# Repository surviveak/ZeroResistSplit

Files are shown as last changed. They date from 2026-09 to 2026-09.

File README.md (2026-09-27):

# ZeroResistSplit

**ZeroResistSplit** is a low-resistance 2-to-1 filament splitter/merger designed for a dedicated TPU path plus a regular-filament path. The goal was to reduce the drag created by steep PTFE bends and abrupt internal transitions while keeping the assembly compact, printable, and compatible with common 4 mm OD PTFE tubing and the original Bambu Lab 4-to-1 PTFE splitter quick-connect fittings.

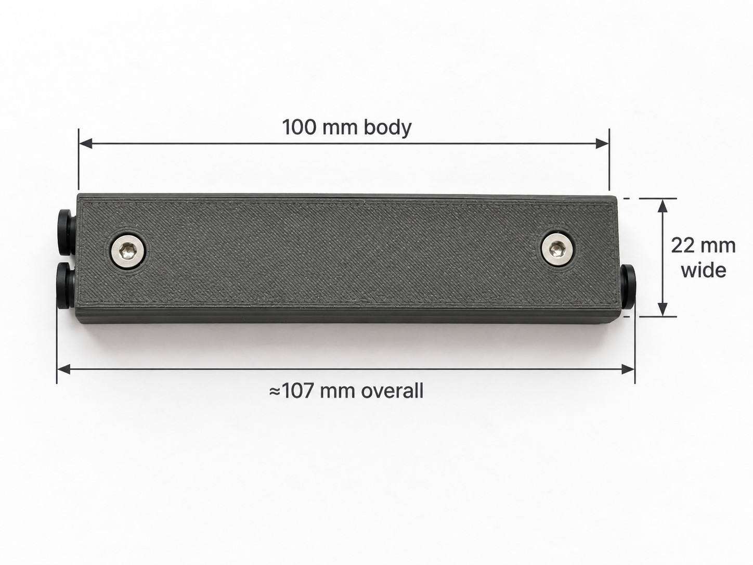
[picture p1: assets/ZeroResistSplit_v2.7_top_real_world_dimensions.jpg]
ZeroResistSplit v2.7 top-view dimensions


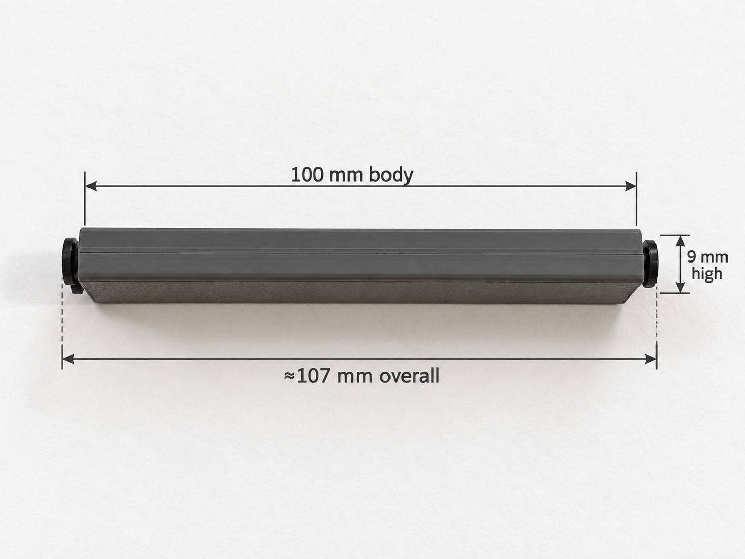
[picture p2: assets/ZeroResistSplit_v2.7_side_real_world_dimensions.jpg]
ZeroResistSplit v2.7 side-view dimensions


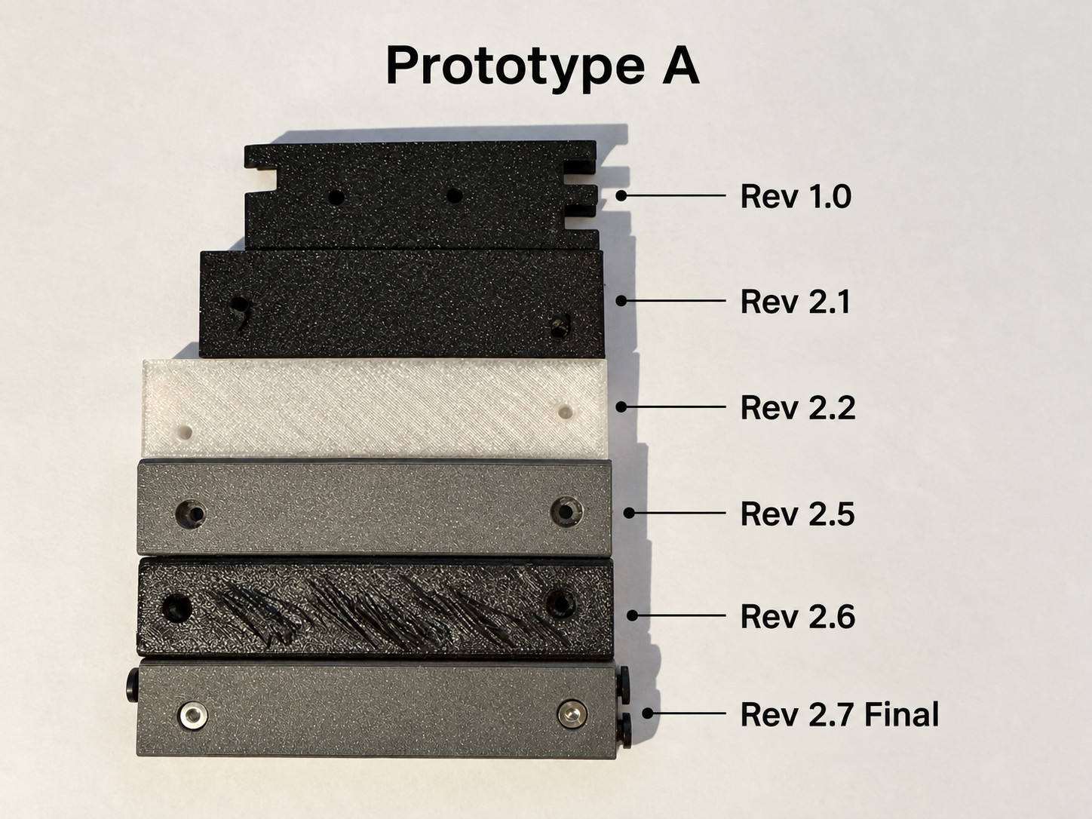
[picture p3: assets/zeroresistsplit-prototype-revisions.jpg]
ZeroResistSplit Prototype A revision progression through v2.7 Final


### Installed on the Bambu Lab H2C

The following photos show the completed v2.7 splitter installed in the working filament path.

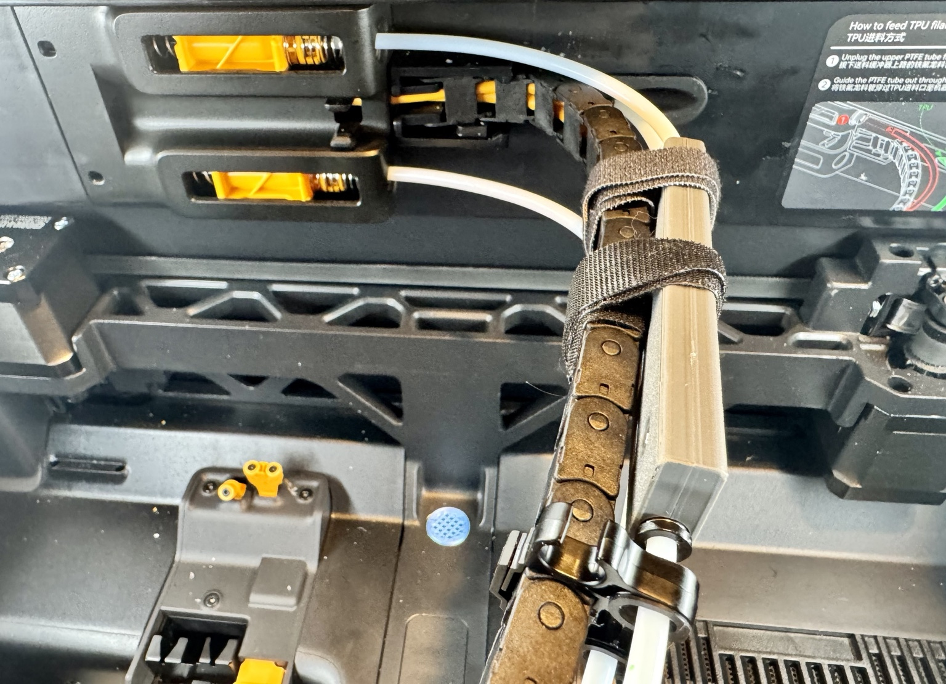
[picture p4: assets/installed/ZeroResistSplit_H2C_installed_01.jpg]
ZeroResistSplit v2.7 installed on Bambu Lab H2C — internal view


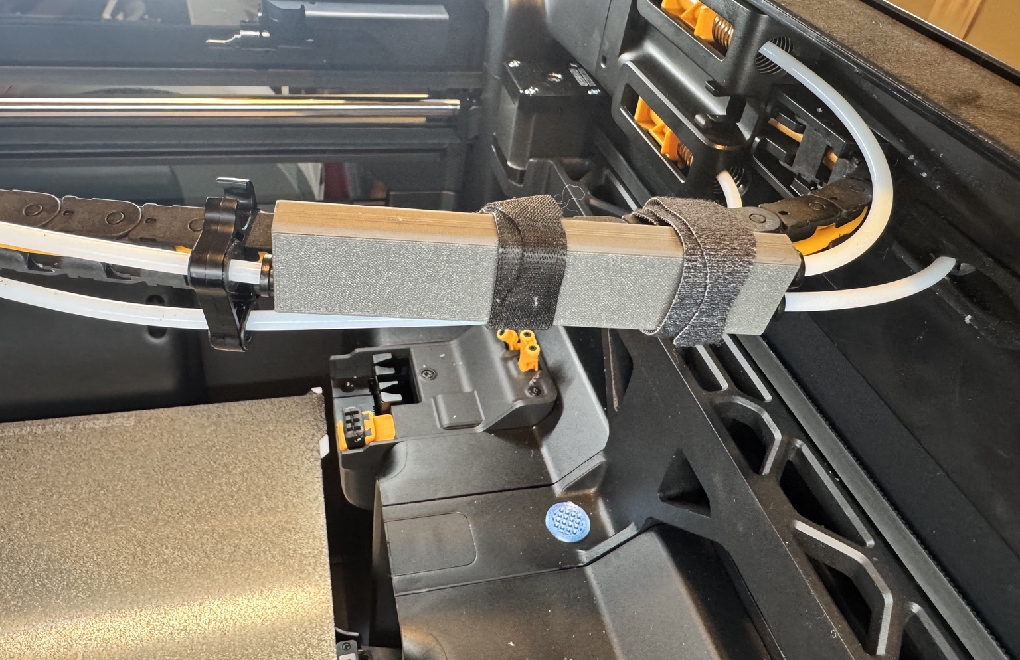
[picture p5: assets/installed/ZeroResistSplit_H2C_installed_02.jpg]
ZeroResistSplit v2.7 installed on Bambu Lab H2C — filament path view


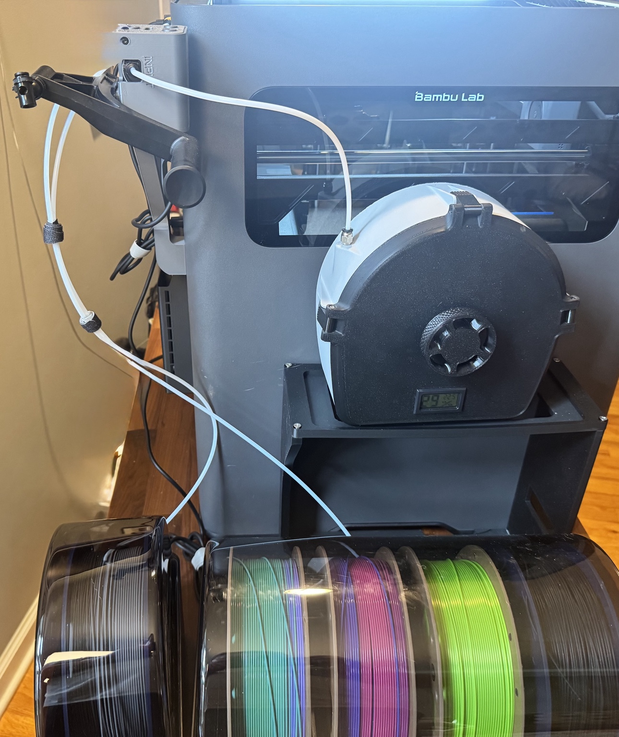
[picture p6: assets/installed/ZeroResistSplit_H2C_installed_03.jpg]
ZeroResistSplit v2.7 installed on Bambu Lab H2C — full setup


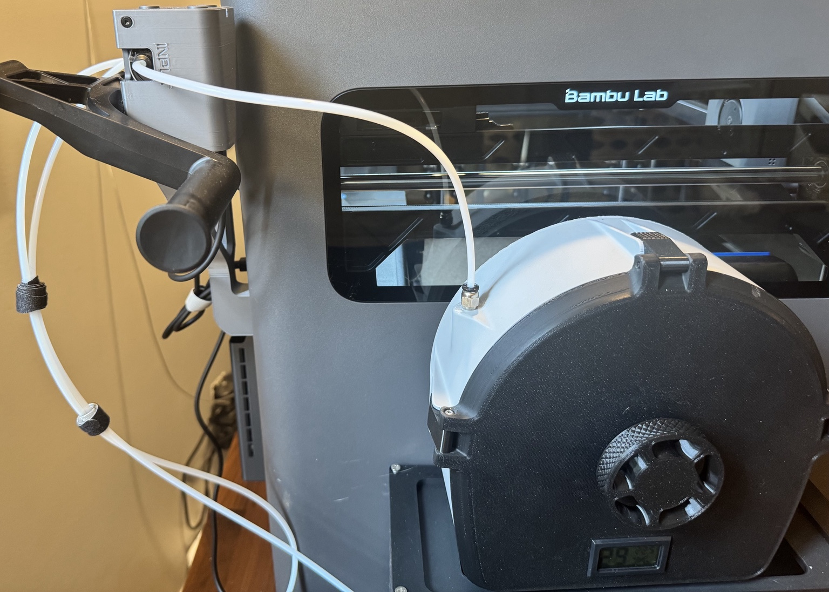
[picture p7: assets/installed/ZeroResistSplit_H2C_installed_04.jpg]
ZeroResistSplit v2.7 installed on Bambu Lab H2C — external routing


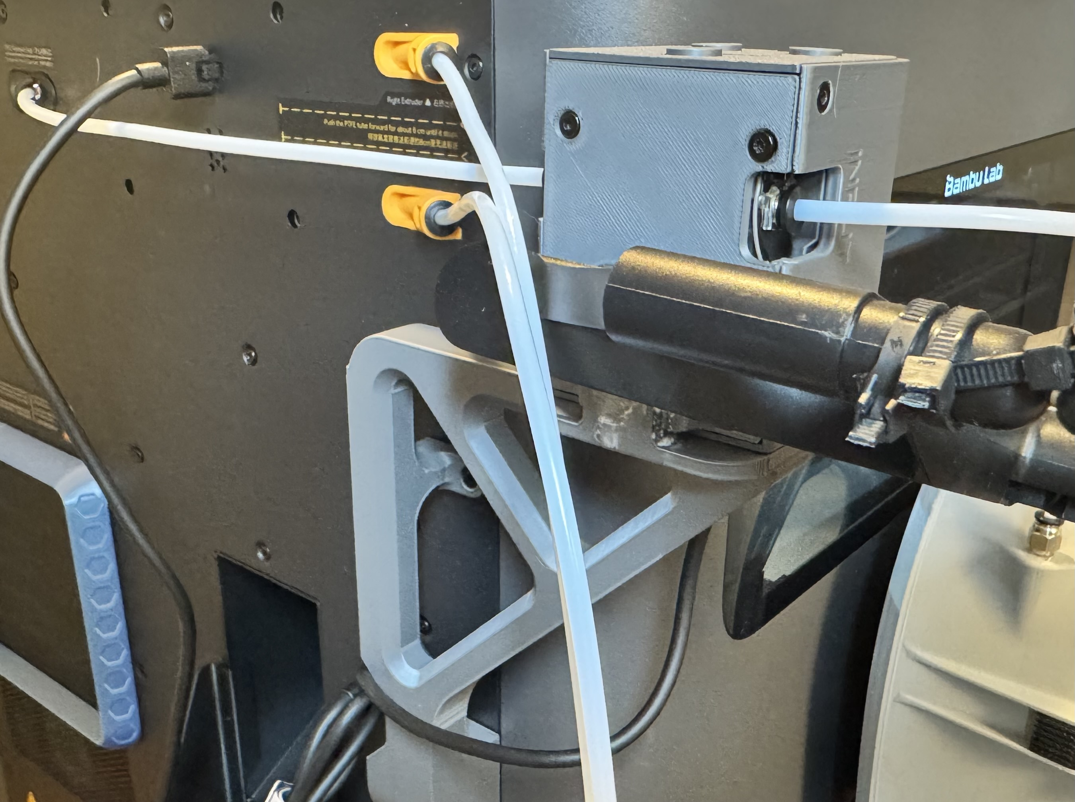
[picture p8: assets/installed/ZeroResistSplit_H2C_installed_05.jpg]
ZeroResistSplit v2.7 installed on Bambu Lab H2C — rear filament routing


The current final prototype is **v2.7**.

## Why this exists

A baseline 2-to-1 splitter used a nearly straight TPU path and a regular-filament path with an approximately 35° transition. Simple pull-force testing showed a large difference:

| Configuration | Path | Approx. pull force |
| --- | --- | ---: |
| Existing 2-to-1 splitter | Straight TPU path | ~0.00 lb |
| Bambu Lab 4-to-1 adapter | Curved path | ~0.33 lb |
| Existing 2-to-1 splitter | ~35° regular path | ~0.75 lb |
| ZeroResistSplit Prototype A v2.2+ | TPU path | Near zero |
| ZeroResistSplit Prototype A v2.2+ | Regular path | Near zero |

These were informal hanging-scale tests, not laboratory measurements. They were used comparatively to guide the design.

## Final design: v2.7

The final design keeps the successful functional geometry developed in Prototype A:

- Straight, low-resistance TPU path.
- Long, shallow regular-filament transition rather than a sharp bend.
- Smooth internal convergence.
- 10 mm straight 2.5 mm guide after the two paths converge so the filament is aligned before entering the output PTFE tube.
- Slightly enlarged internal free-travel region while preserving a 2.5 mm interface at the PTFE tube ends.
- 4.0 mm PTFE tube bores.
- 7.1 mm quick-connect fitting recesses, 5 mm deep.
- PTFE tubing extends 10 mm beyond each quick-connect fitting into the body.
- Rounded/bullnosed exterior edges.
- Two-piece clamshell body.
- M3 screw fastening with recessed hex-head screws and blind self-tapping pilot holes in the mating half.
- No nuts required.

### Final dimensions

- Overall body: **100 x 22 x 9 mm**
- Nominal quick-connect fitting OD: **7.0 mm**
- Printed quick-connect recess: **7.1 mm diameter x 5.0 mm deep**
- PTFE tubing: **4.0 mm OD / approximately 2.5 mm ID**
- PTFE guide bore: **4.0 mm**
- Filament interface diameter: **2.5 mm**
- Enlarged internal guide region: up to approximately **3.6 mm**
- Straight post-convergence alignment section: **10 mm**
- Exterior bullnose radius: **1.8 mm**
- M3 clearance hole: **3.2 mm**
- M3 blind pilot: **2.6 mm**
- Screw-head recess diameter: **6.4 mm**
- Screw-head recess depth: **1.5 mm**

## Files

- `models/PTFE_Splitter_A_v2.7_Half1.stl` — print-ready half 1
- `models/PTFE_Splitter_A_v2.7_Half2.stl` — print-ready half 2
- `source/PTFE_Splitter_A_v2.7.scad` — parametric source used to generate the final STLs
- `docs/DESIGN_SPEC.md` — detailed geometry and design rationale
- `docs/PRINTING_AND_ASSEMBLY.md` — print, hardware, and assembly notes
- `docs/TESTING.md` — pull-force testing notes and results
- `docs/DEVELOPMENT_HISTORY.md` — prototype and revision history

## Printing

The final prototype has been successfully printed and assembled. A stronger engineering filament such as **ABS** is useful for additional toughness, but **PETG or PLA also work** for this application.

A thin layer of glue at the mating/contact points can help keep the assembly extremely tight and can help retain the quick-connect fittings.

See [Printing and Assembly](docs/PRINTING_AND_ASSEMBLY.md) for details.

## Hardware

The tested build reuses the **three PTFE quick-release/quick-connect fittings directly from an original Bambu Lab 4-to-1 PTFE splitter**. The printed recesses were tuned around those actual fittings.

Typical build:

- 3 x PTFE quick-connect fittings removed from a Bambu Lab 4-to-1 PTFE splitter
- 4 mm OD / ~2.5 mm ID PTFE tube
- 2 x M3 hex-head screws
- Optional small amount of adhesive

## Design status

**v2.7 is the current final tested design.** Resistance is minimal on both paths and filament feeds smoothly through both routes.

This project was developed iteratively through physical printing, fit checks, and comparative pull-force testing.

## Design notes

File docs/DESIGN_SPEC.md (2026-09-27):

# Design Specification — ZeroResistSplit v2.7

## Functional goal

ZeroResistSplit is a 2-to-1 PTFE filament splitter/merger intended to provide:

1. A nearly frictionless straight path for TPU.
2. A low-resistance regular-filament path with a long, shallow transition instead of the approximately 35° bend used by the original reference splitter.
3. Smooth transitions between 4 mm OD PTFE tubing and the printed internal filament guide.
4. A compact, rigid, two-piece body that can be printed on a typical FDM printer and assembled with M3 screws.

The final v2.7 geometry is based on the tested v2.2 functional layout. Later revisions only refined the exterior, connector fit, and screw-head recess.

## Overall envelope

| Parameter | Final value |
| --- | ---: |
| Length | 100 mm |
| Width | 22 mm |
| Height | 9 mm |
| Exterior long-edge bullnose radius | 1.8 mm |

The input and output fitting faces remain flat.

## PTFE and connector interfaces

The final physical build uses the **three original PTFE quick-release/quick-connect fittings removed from a Bambu Lab 4-to-1 PTFE splitter**. The fitting recess dimensions below were tuned by printing and testing against those actual Bambu parts.

| Feature | Final value |
| --- | ---: |
| Nominal quick-connect fitting OD | 7.0 mm |
| Printed quick-connect recess | 7.1 mm diameter |
| Quick-connect recess depth | 5.0 mm |
| PTFE tube OD | 4.0 mm |
| PTFE nominal ID | ~2.5 mm |
| Printed PTFE guide bore | 4.0 mm |
| PTFE extension beyond fitting into body | 10 mm on all 3 ports |

The 7.1 mm fitting recess was chosen after physical fit testing with the original Bambu Lab 4-to-1 fittings. The earlier 7.2 mm recess was slightly too loose and could allow fittings to pull out.

The PTFE bore remains 4.0 mm. It should not be enlarged to solve fitting-fit issues; fitting clearance is controlled separately by the 7.1 mm connector recess.

Third-party quick-connect fittings may differ dimensionally and should be measured before assuming a direct fit.

## Internal filament guide

The 2.5 mm dimension is treated as the required interface size where the printed guide meets the PTFE tube, not as a mandatory diameter through the entire internal path.

| Feature | Final value |
| --- | ---: |
| Filament/PTFE interface diameter | 2.5 mm |
| Maximum enlarged internal guide diameter | ~3.6 mm |
| Straight output alignment section | 10 mm |

The slightly larger internal guide allows the filament to move without unnecessary wall contact while the 2.5 mm interfaces keep the filament centered at the PTFE tube ends.

### Coordinate layout used by the parametric source

The source uses the following path locations in millimeters:

- Regular-filament input centerline: **Y = +4.8**
- TPU input centerline: **Y = -4.8**
- Output centerline: **Y = -4.8**
- End of both input PTFE tubes: **X = 15**
- Path convergence: **X = 75**
- Start/end face of output PTFE guide: **X = 85**
- Output face: **X = 100**

This provides a **10 mm straight 2.5 mm alignment run between X = 75 and X = 85** after convergence and before the filament enters the output PTFE tube.

## Regular-filament path

The regular path transitions from the upper input to the output centerline using a long cosine-eased curve. This provides tangent-like behavior at both ends rather than a sharp change of direction.

The design goal evolved from simply reducing the original ~35° path angle to minimizing total drag over the entire path. Physical testing showed this geometry was more important than forcing a specific theoretical angle.

## TPU path

The TPU path stays aligned with the output centerline and remains effectively straight through the splitter. The printed guide can open slightly in the free-travel region but returns to 2.5 mm at the interfaces.

This preserves the lowest-resistance characteristic observed in the original straight-path testing.

## Convergence and output alignment

A key v2.2 improvement was adding **10 mm of straight guide after the paths converge**. During earlier testing, regular filament could reach the output PTFE while still angled and catch the lower edge of the tube.

The 10 mm straight section allows the filament to straighten and center before entering the output PTFE. This eliminated the noticeable transition snap in testing.

## Fasteners

The body uses two M3 screws with no nuts.

| Feature | Final value |
| --- | ---: |
| Upper-half M3 clearance hole | 3.2 mm |
| Lower-half blind pilot | 2.6 mm |
| Screw-head recess diameter | 6.4 mm |
| Screw-head recess depth | 1.5 mm |
| Input-side screw center | X 9, Y 0 |
| Output-side screw center | X 88, Y +1.5 |

The lower-half pilot holes stop before the outside surface so the M3 screws thread directly into the printed plastic.

The screw locations were chosen to stay away from the filament tracks. Earlier prototype screw locations that intersected the filament path were rejected.

## Exterior refinement

The final exterior was intentionally kept mostly rectangular rather than tightly following the Y-path. The goals were:

- Retain enough material around the screw holes.
- Avoid an awkward isolated output screw boss.
- Keep a clean visual appearance.
- Round the long edges for comfort and appearance.
- Preserve all tested v2.2 functional geometry.

## Source of truth

The final parametric source is:

`source/PTFE_Splitter_A_v2.7.scad`

The final printable parts are:

- `models/PTFE_Splitter_A_v2.7_Half1.stl`
- `models/PTFE_Splitter_A_v2.7_Half2.stl`

The comments in the source file record the design constraints that should remain locked if future revisions are made.

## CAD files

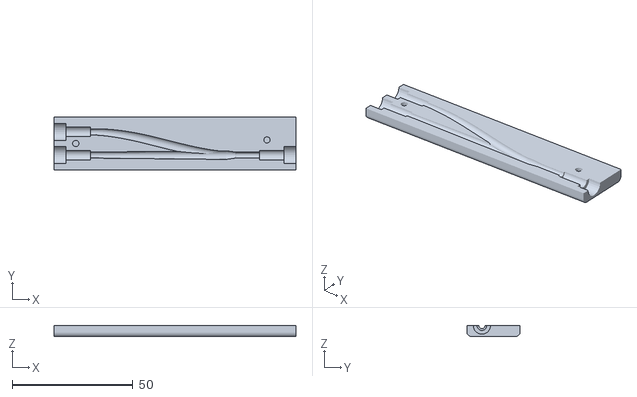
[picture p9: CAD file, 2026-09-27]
models/PTFE_Splitter_A_v2.7_Half1.stl
100.0 x 22.0 x 4.52

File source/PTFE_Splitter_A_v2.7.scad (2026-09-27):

// PTFE Splitter A v2.7 - screw recess refinement
// Units: mm
// SOURCE OF TRUTH: v2.2 functional geometry.
// Functional geometry remains the proven v2.2 design.
// v2.7 refinement from v2.6:
//   - Reduce M3 screw-head counterbore depth from 2.00 mm to 1.50 mm.
//   - All other v2.6 geometry is unchanged, including 7.10 mm quick-release recesses,
//     4.00 mm PTFE bores, proven v2.2 filament paths, and exterior form.
// Exterior / fastening refinements only:
//   - More rectangular 22 mm-wide body (v2.2 was 24 mm), no aggressive waist/indent.
//   - 1.8 mm bullnose radius on the four long exterior edges; end faces remain flat for fittings.
//   - Input screw remains at v2.2 location.
//   - Output screw moved inward to a better-supported centered location, clear of the filament/PTFE path.
//   - M3 screw-head counterbores added; lower half retains blind self-tapping pilots (no nuts).
// All v2.2 filament-path centerlines, angles, convergence point, channel diameters,
// straightening length and PTFE insertion lengths are preserved. Exterior refinements from v2.4 are preserved.

$fn=28;
halfpart=is_undef(halfpart)?0:halfpart;

L=100;
W=22;
H=9;
edge_r=1.8;

connector_nominal_d=7.0;
connector_recess_d=7.10;
connector_depth=5.0;
ptfe_od_nominal=4.0;
ptfe_guide_d=4.00;
filament_d=2.5;
mid_d=3.6;

yn=4.8;
yt=-4.8;
yo=yt;
input_tube_beyond=10.0;
output_tube_beyond=10.0;
normal_tip=connector_depth+input_tube_beyond;
TPU_tip=normal_tip;
output_tip=L-(connector_depth+output_tube_beyond);
converge_x=output_tip-10.0;

screw1=[9,0];
screw2=[88,1.5];
clear_d=3.2;
pilot_d=2.6;
head_d=6.4;
head_depth=1.5;

module seg(p1,p2,d1,d2){
    hull(){
        translate(p1) sphere(d=d1);
        translate(p2) sphere(d=d2);
    }
}
function ease(t)=0.5-0.5*cos(180*t);
function dia(t)=filament_d+(mid_d-filament_d)*sin(180*t);

module eased(y0,y1,x0,x1,n=18){
    for(i=[0:n-1]){
        t1=i/n; t2=(i+1)/n;
        seg([x0+(x1-x0)*t1, y0+(y1-y0)*ease(t1), 0],
            [x0+(x1-x0)*t2, y0+(y1-y0)*ease(t2), 0],
            dia(t1), dia(t2));
    }
}

module xcyl(x1,x2,y,d){
    translate([x1,y,0]) rotate([0,90,0]) cylinder(h=x2-x1,d=d);
}

module filament_and_connector_cuts(){
    xcyl(0,connector_depth,yn,connector_recess_d);
    xcyl(0,connector_depth,yt,connector_recess_d);
    xcyl(L-connector_depth,L,yo,connector_recess_d);

    xcyl(0,normal_tip,yn,ptfe_guide_d);
    xcyl(0,TPU_tip,yt,ptfe_guide_d);
    xcyl(output_tip,L,yo,ptfe_guide_d);

    eased(yn,yo,normal_tip,converge_x);
    seg([TPU_tip,yt,0],[converge_x-4,yo,0],filament_d,mid_d);
    seg([converge_x-4,yo,0],[converge_x,yo,0],mid_d,filament_d);
    xcyl(converge_x,output_tip,yo,filament_d);
}

module body_solid(){
    hull(){
        for(y=[-W/2+edge_r, W/2-edge_r])
            for(z=[-H/2+edge_r, H/2-edge_r])
                translate([0,y,z]) rotate([0,90,0]) cylinder(h=L,r=edge_r);
    }
}

module base_without_screws(){
    difference(){
        body_solid();
        filament_and_connector_cuts();
    }
}

module lower(){
    difference(){
        intersection(){
            base_without_screws();
            translate([-1,-W,-H/2-.02]) cube([L+2,2*W,H/2+.04]);
        }
        for(p=[screw1,screw2])
            translate([p[0],p[1],-H/2+1.0]) cylinder(h=H/2-1.0+.05,d=pilot_d);
    }
}

module upper(){
    difference(){
        intersection(){
            base_without_screws();
            translate([-1,-W,0]) cube([L+2,2*W,H/2+.02]);
        }
        for(p=[screw1,screw2]){
            translate([p[0],p[1],-.05]) cylinder(h=H/2+.1,d=clear_d);
            translate([p[0],p[1],H/2-head_depth]) cylinder(h=head_depth+.1,d=head_d);
        }
    }
}

if(halfpart==0) union(){ lower(); upper(); }
if(halfpart==1) translate([0,0,H/2]) lower();
if(halfpart==2) translate([0,0,H/2]) rotate([180,0,0]) upper();

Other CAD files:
models/PTFE_Splitter_A_v2.7_Half2.stl

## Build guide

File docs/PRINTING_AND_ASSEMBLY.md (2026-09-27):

# Printing and Assembly — ZeroResistSplit v2.7

## Recommended materials

The final prototype works in common FDM materials.

- **ABS:** Recommended when additional toughness and heat resistance are desired.
- **PETG:** A good general-purpose choice and fully suitable for this design.
- **PLA:** Also works for normal use.

A stronger engineering filament is helpful, but it is not required for the splitter to function correctly.

## Print files

Print both halves:

- `models/PTFE_Splitter_A_v2.7_Half1.stl`
- `models/PTFE_Splitter_A_v2.7_Half2.stl`

The two halves are designed to be assembled as a clamshell around the internal paths.

## Hardware

The tested final assembly reuses the **three PTFE quick-release/quick-connect fittings from an original Bambu Lab 4-to-1 PTFE splitter**. They were removed from the existing Bambu unit and installed directly into ZeroResistSplit. The connector recess dimensions in v2.7 were tuned around these parts.

Recommended hardware:

- 3 x original Bambu Lab 4-to-1 PTFE splitter quick-connect fittings
- 4 mm OD / approximately 2.5 mm ID PTFE tubing
- 2 x M3 hex-head screws
- Optional small amount of adhesive

No nuts are required. One printed half has M3 clearance holes; the mating half has blind pilot holes intended for the M3 screws to self-tap into the plastic.

## Fitting and PTFE installation

Each port is designed as:

1. **7.1 mm diameter x 5 mm deep quick-connect fitting recess**
2. **4.0 mm PTFE guide bore**
3. PTFE tubing extending **10 mm past the fitting** into the body
4. Printed filament guide meeting the PTFE at a **2.5 mm filament opening**

The reused Bambu Lab quick-connect fitting has an inserted outside diameter of approximately 7.0 mm. The final printed recess is 7.1 mm after physical fit testing with those original Bambu fittings.

### Important

Do not enlarge the 4.0 mm PTFE bore to compensate for quick-connect fitting fit. The connector recess and PTFE bore serve different functions and should be adjusted independently.

Because the final fit was developed around the original Bambu Lab 4-to-1 fittings, third-party fittings with different outside dimensions may require a connector-recess adjustment.

## Adhesive

A **very thin layer of glue at the contact points** can be used during final assembly.

This was found to help:

- Keep the two halves extremely tight.
- Keep the quick-connect fittings firmly seated.
- Reduce any possibility of movement during filament loading/unloading.

Use only a thin amount so adhesive does not enter the filament tracks, PTFE bores, or quick-connect mechanisms.

## Screws

The final design uses **M3 hex-head screws**.

- Upper-half clearance: 3.2 mm
- Lower-half blind pilot: 2.6 mm
- Head recess: 6.4 mm diameter x 1.5 mm deep

Tighten only enough to close the seam and hold the assembly securely. Over-tightening can strip a printed pilot hole or deform the body.

## Fit checks before use

Before installing the splitter on a printer:

1. Confirm all three quick-connect fittings seat fully and do not wobble.
2. Confirm the PTFE tubes extend through their guide bores and reach the internal termination points.
3. Close the two halves and confirm the seam closes fully.
4. Install and tighten the two M3 screws.
5. Manually push a piece of rigid filament through the regular path.
6. Manually push TPU through the straight TPU path.
7. Confirm both filaments pass through the output PTFE without catching.

The final design should feel smooth through both paths with minimal resistance.

## Surface finish

The tested design performed well directly from the printer. If desired, exposed internal guide surfaces can be lightly smoothed before assembly, but avoid changing the 2.5 mm PTFE-interface geometry.

The largest resistance reduction came from the path geometry rather than from exotic low-friction materials or coatings.

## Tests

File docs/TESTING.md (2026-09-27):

# Testing Notes — ZeroResistSplit

## Test method

Development used a simple comparative pull-force test:

- A piece of filament was routed through the adapter.
- A hanging scale was attached to the filament.
- The filament was pulled through the path.
- The displayed force was used as a comparative measure of resistance.

This was an informal development test, not a calibrated laboratory friction measurement. Pull speed, filament condition, scale resolution, and hand technique can affect the numbers.

The results are most useful as **relative comparisons between geometries**.

## Baseline results

| Adapter | Path | Approx. pull force |
| --- | --- | ---: |
| Original 2-to-1 | Straight TPU path | ~0.00 lb |
| Bambu Lab 4-to-1 | Curved path | ~0.33 lb |
| Original 2-to-1 | Regular path, ~35° transition | ~0.75 lb |

The original regular path required more than twice the measured force of the Bambu 4-to-1 path in the informal test.

## Design conclusion from baseline testing

The results indicated that path geometry was the dominant problem:

- The straight TPU route had effectively unmeasurable resistance using the scale.
- The short, steep ~35° regular path had the highest resistance.
- A longer, shallower transition was more important than simply changing printed material or polishing the channel.

This led to Prototype A: preserve the straight TPU route and substantially lengthen/soften the regular-filament transition.

## Prototype A / v2.2 result

After correcting the connector/PTFE interfaces and internal path, Prototype A Rev 2 showed a major improvement:

- TPU path: **near-zero resistance**
- Regular-filament path: **near-zero resistance**
- Quick-connect fittings and PTFE fit correctly.
- Filament followed both paths smoothly.

The one remaining feed issue was a small snap as regular filament transitioned into the output PTFE. The filament was still slightly angled when it reached the tube edge.

## Output straightening improvement

To solve the output transition, v2.2 added:

- **10 mm more straight printed filament guide after convergence**
- Output PTFE extension increased to **10 mm beyond the quick-connect fitting**

This gave the regular filament time to straighten before meeting the output PTFE and produced smooth feeding through the final design.

## Final v2.7 behavior

The final printed v2.7 design was reported to have:

- Minimal resistance.
- Smooth TPU feeding.
- Smooth regular-filament feeding.
- Good mechanical fit.
- Secure quick-connect fittings when assembled with a thin layer of adhesive.
- Good results in engineering filament, while remaining printable in PETG or PLA.

## Suggested repeatable test procedure

For future comparisons:

1. Use the same piece/type of filament for each path when possible.
2. Use the same pull distance.
3. Pull at a similar slow, steady speed.
4. Ignore the initial breakaway peak if measuring steady-state drag.
5. Perform at least 5 pulls per path.
6. Record the average and range.
7. Repeat for PLA, PETG, and TPU if comparing material behavior.

A more rigorous future setup could use a fixed-speed motorized pull and a digital force gauge, but that is not necessary for normal validation of this design.

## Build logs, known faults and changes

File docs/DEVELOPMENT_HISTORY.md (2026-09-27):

# Development History

This document summarizes the design path that led to the final ZeroResistSplit v2.7.

## Starting point

The original 2-to-1 adapter was approximately 40 mm long and had:

- A straight/direct TPU path that worked extremely well.
- A regular-filament path with an approximately 35° transition.
- Considerably more drag on the regular path.

Informal pull-force results:

- Straight TPU path: ~0.00 lb
- Regular ~35° path: ~0.75 lb
- Bambu Lab 4-to-1 comparison: ~0.33 lb

The goal became preserving the straight TPU path while giving the regular path a much longer, shallower transition.

The final ZeroResistSplit assembly also deliberately **reuses the three PTFE quick-release/quick-connect fittings from the original Bambu Lab 4-to-1 PTFE splitter** rather than replacing them with generic fittings.

## Early concept work

Two concepts were considered:

### Prototype A — straight TPU path

- Keep TPU aligned directly with the output.
- Use available body length to soften the regular-filament transition.
- Preserve the lowest possible TPU resistance.

### Prototype B — symmetric bends

- Bend both input paths slightly toward a centered output.
- Split the total directional change between the two paths.

Testing Prototype A showed such low resistance on both paths that Prototype B was no longer necessary.

## Prototype A — first physical test

The first printed prototype demonstrated that the filament-path concept felt correct, but exposed several mechanical problems:

- Missing PTFE insertion/guide features.
- Screw holes crossed the filament tracks.
- Quick-connect fitting recess geometry was incorrect.

These were corrected rather than changing the promising path geometry.

## Interface corrections

Measured/confirmed hardware dimensions:

- PTFE OD: 4.0 mm
- PTFE ID: approximately 2.5 mm
- Bambu Lab 4-to-1 quick-connect inserted OD: approximately 7.0 mm
- Quick-connect insertion depth: 5 mm

The three quick-connect fittings used for development and the final build were taken directly from the existing Bambu Lab 4-to-1 PTFE splitter. This allowed the new printed body to reuse known-good Bambu hardware.

The design was updated so the PTFE tube, not an oversized printed void, continues beyond the fitting before meeting the internal filament guide.

Final concept:

`quick-connect recess -> 4 mm PTFE bore -> 2.5 mm filament interface -> enlarged internal guide`

## v2.1 / Rev 2 functional breakthrough

With the corrected fittings and tube guides:

- Hardware fit properly.
- TPU resistance remained near zero.
- Regular-path resistance also became near zero.

This validated the long, shallow regular-filament path.

## v2.2 — output transition refinement

A minor catch remained when regular filament entered the output PTFE. It approached the tube slightly angled and could touch the lower edge.

Changes:

- Added 10 mm of straight 2.5 mm guide after convergence.
- Increased output PTFE extension to 10 mm beyond its quick-connect fitting.
- Changed screw design so M3 screws pass through one half and self-tap into blind pilots in the other half.
- No nuts required.

This became the frozen functional baseline.

## Exterior refinements

After v2.2 worked well, development shifted to aesthetics and packaging while preserving the internal geometry.

Requested exterior direction:

- More rectangular body.
- Rounded/bullnosed edges.
- Avoid dramatic side indentation.
- Recess M3 screw heads.
- Keep screw placement away from filament tracks.
- Move output screw into a better-supported location.

The functional v2.2 path geometry remained locked.

## v2.4

Exterior was narrowed to 22 mm and given 1.8 mm bullnose edges. The output screw position was improved and head recesses were added.

An attempted 4.2 mm PTFE guide tolerance was rejected because the fit issue was actually at the quick-connect fittings, not the PTFE tube.

## v2.5

- PTFE guide returned to the correct 4.0 mm diameter.
- Quick-connect recess increased to 7.2 mm for fit testing.

The overall design was the best version at that point, but the quick-connect recess was slightly too loose.

## v2.6

- Quick-connect recess reduced to 7.1 mm.
- Screw-head recess depth reduced to 2.0 mm.

Everything else remained unchanged.

## v2.7 — final

Final minor adjustment:

- Screw-head recess depth reduced from 2.0 mm to **1.5 mm**.

Final tested notes:

- Design printed successfully.
- Minimal resistance on both paths.
- ABS is useful for a stronger engineering build, but PETG and PLA are also suitable.
- A thin layer of glue at contact points helps keep the body and quick-connect fittings extremely secure.
- M3 hex-head screws are used.
- The three quick-connect fittings in the tested final assembly are the original parts removed from a Bambu Lab 4-to-1 PTFE splitter.

v2.7 is the current final design.

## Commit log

2026-09-27 Add printing and assembly guide
2026-09-27 Document prototype and revision history
2026-09-27 Add v2.7 parametric source
    [PTFE_Splitter_A_v2.7.scad]
2026-09-27 Add reproducible STL build workflow
2026-09-27 Build v2.7 STL files [skip ci]
    [PTFE_Splitter_A_v2.7_Half1.stl, PTFE_Splitter_A_v2.7_Half2.stl]
2026-09-27 Document reuse of Bambu Lab 4-to-1 PTFE connectors
2026-09-27 Add prototype revision comparison photo
2026-09-27 Add final dimensions and prototype progression photos to README
